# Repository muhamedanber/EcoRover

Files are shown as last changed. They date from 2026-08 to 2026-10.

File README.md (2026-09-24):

# EcoRover
A motorized recycling bin targeting food courts with a built-in fridge to store food left-overs so other people can use it. Helping saving our planet, achive SDGs 2, 8, 9, 11, 12, and 13 and increasing social Interdependence! (A Stardance project)

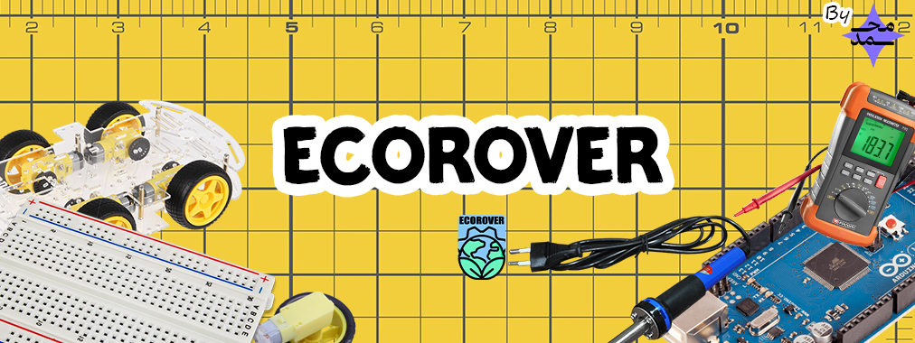
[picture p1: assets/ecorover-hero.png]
EcoRover Hero


<div align="center">
github logos
</div>
    &nbsp;&nbsp;

<p align="center"> 
  
  
</p>

</div>

</div>

> **Note on AI Usage:**  about the usage of AI: The AI is being used in this project to generate ideas, explain and debug. However, it's not used to create parts of the project that require creativity, design and construction. Also, the AI is not used more than 10% of the total project. Which counts as MADE BY HUMAN.

> **The currnt state: Working on the electronics. View [`JOURNAL.md`](./JOURNAL.md)**

---

## 1st The project and It's goals:

It’s a fancy trashcan after all XD, it has 5 wheels and sensors, and it’s gonna be wandering around in food courts with a built-in fridge. And it’s gonna store food leftovers (along with functioning like a recycling bin obviously). That way, whenever someone needs food, they can just take it without having to ask anyone, keeping their dignity completely intact. While still serving as a trash can with 4 holes so it can be recycled later.

1. 🇪🇬 Support Youth-Led Egyptian Projects: Proving what young Egyptian engineers can build from the ground up (like me XD).
2. 🇺🇳 Sustainable Development Goals: Promote both global and local sustainability by aligning with UN Sustainable Development Goals 2, 8, 9, 11, 12, and 13 (This isn’t planned; I found out halfway through the project lol).
3. 🫂 Developing Social Solidarity: Protecting human dignity while reducing food waste by making leftover food accessible without friction or embarrassment.
4. 🧠 Empower Human Intelligence: Using AI merely as a tool to increase productivity rather than as a source of creativity, since this project was developed with less than 10% AI assistance.
5. 🌍 Protect the Planet: Help protect the planet by removing organic waste and recyclables from landfills to reduce CO2 emissions and tackle environmental waste.
   
---

## 2nd Features

Here's everything packed into EcoRover to make it actually work out in the wild (
aka food courts):

* **Built-in Leftover Fridge:** Keeps uncontaminated leftover food fresh and chilled right inside the rover, giving anyone who needs a meal direct access to it without having to ask anyone or feel awkward.
* **4-Way Trash Separator:** Built into the top tier so people can sort recyclables and waste on the fly instead of tossing everything into one pile.
* **Autonomous Navigation:** Powered by an array of 8 HC-SR04 ultrasonic sensors that continuously scan all directions to dodge people, tables, and obstacles while wandering around.
* **Custom 3-Tier Modular Structure:** Modeled in Fusion 360 with a compact 40x30cm footprint and an ergonomic 90cm standing height so users don't have to bend over to toss waste or grab food.
* **Safety & Indicator System:** Includes an onboard buzzer and directional rear LEDs to signal movement (turning left, right, or stopping) so people in crowded areas see and hear it coming.
* **Dedicated Power & Driver Tier:** A low center of gravity bottom compartment housing the battery, motor drivers, and motors to keep the rover stable while moving.
* **Instant-On Active Cooling:** System firmware fires up the fridge unit immediately on boot up to ensure food stays safe from the moment the rover starts running.

---

## 3rd The CAD

The project is made of 3 main parts with a footprint of 40x30cm and moddeled into fusion 360 (my first time cadding).

* **Bottom tier:** 10cm for the battery, motors and H bridges, and counterweights if needed.

| Bottom Figure Render | Bot Bottom Figure | Bottom Body Sketch |
| :---: | :---: | :---: |
| Bottom Figure Render | Bot Body figure V1 | Bot Body sketch

* **Middle tier:** The fridge and logic board layer, 45cm.

| Mid Body Figure V2 | Mid Figure Render | Mid Body Sketch |
| :---: | :---: | :---: |
| Mid Body figure V2 | Mid Figure Render | Mid Body sketch |

* **Top tier:** The trash seprator compartment, 35cm.
  
| Top Figure V2 | Top Figure Render | Top Body Sketch |
| :---: | :---: | :---: |
| Top figure V2 | Top Figure Render | Top Body sketch |

When I first started, Gemini suggested a 40x30cm footprint and 60cm height. I just started drawing it and didn’t notice it was way too short, making the trash compartment totally inaccessible and the fridge way too tiny. I didn’t notice till I was already cadding. Since 30x40cm is a good footprint, I decided to keep that, but when I pulled out a physical tape measure and imagined the project, I found myself bending over just to reach that height! So, I pushed it up to 90cm, which feels much better. Gemini assumed I would use heavy materials, but I’m going lightweight, so Inshallah it won’t tip over.

---

## 4th The Firmware

The firmware manages everything, takes the signal from the 8 HC-SR04 ultrasonic sensors, and calculates the distance in all directions; based on that, it decides its move (moveForward, moveBackward, spinLeft, spinRight, and stop). On setup, it runs the cooling system immediately, and it also manages the safety indicators system (Buzzer and back LEDs for right and left)

Check it out at [`src-pre-release.ino`](./Firmwear/src-pre-release.ino)

---

## 5th The wiring

The wiring was done in order to create a BOM, i used fritzing even though i'm dummy at it. It went through 2 iterations, and I'm sure I've got some connections wrong, but it's only to visualize things. Both of them are missing the movmet safty system, but it has the crucial electrical safety system on V2. And to prevent electrical fire, I reached out to a fellow engineer, Mustafa Qusit (a mechatronics engineer and currently a B1 aircraft maintenance engineer at EgyptAir), to get his feedback on my circuit setup. Huge shout-out to him! He was super supportive, though he made it clear he won’t give me direct shortcuts on the electronics. He wants me to learn through trial and error, but he promised he’d step in and tell me if anything I wired is genuinely dangerous or going to go kaboom. If it’s safe, he’s letting me figure out the best way on my own, which I really respect. (Update: the boaed is changed to an UNO, check the journal to know why 🍞🍳) 

| EcoRover V2 | EcoRover V1 | EcoRover V3 |
| :---: | :---: | :---: |
| EcoRover_v2 | EcoRover_v1 | EcoRover_v3 |

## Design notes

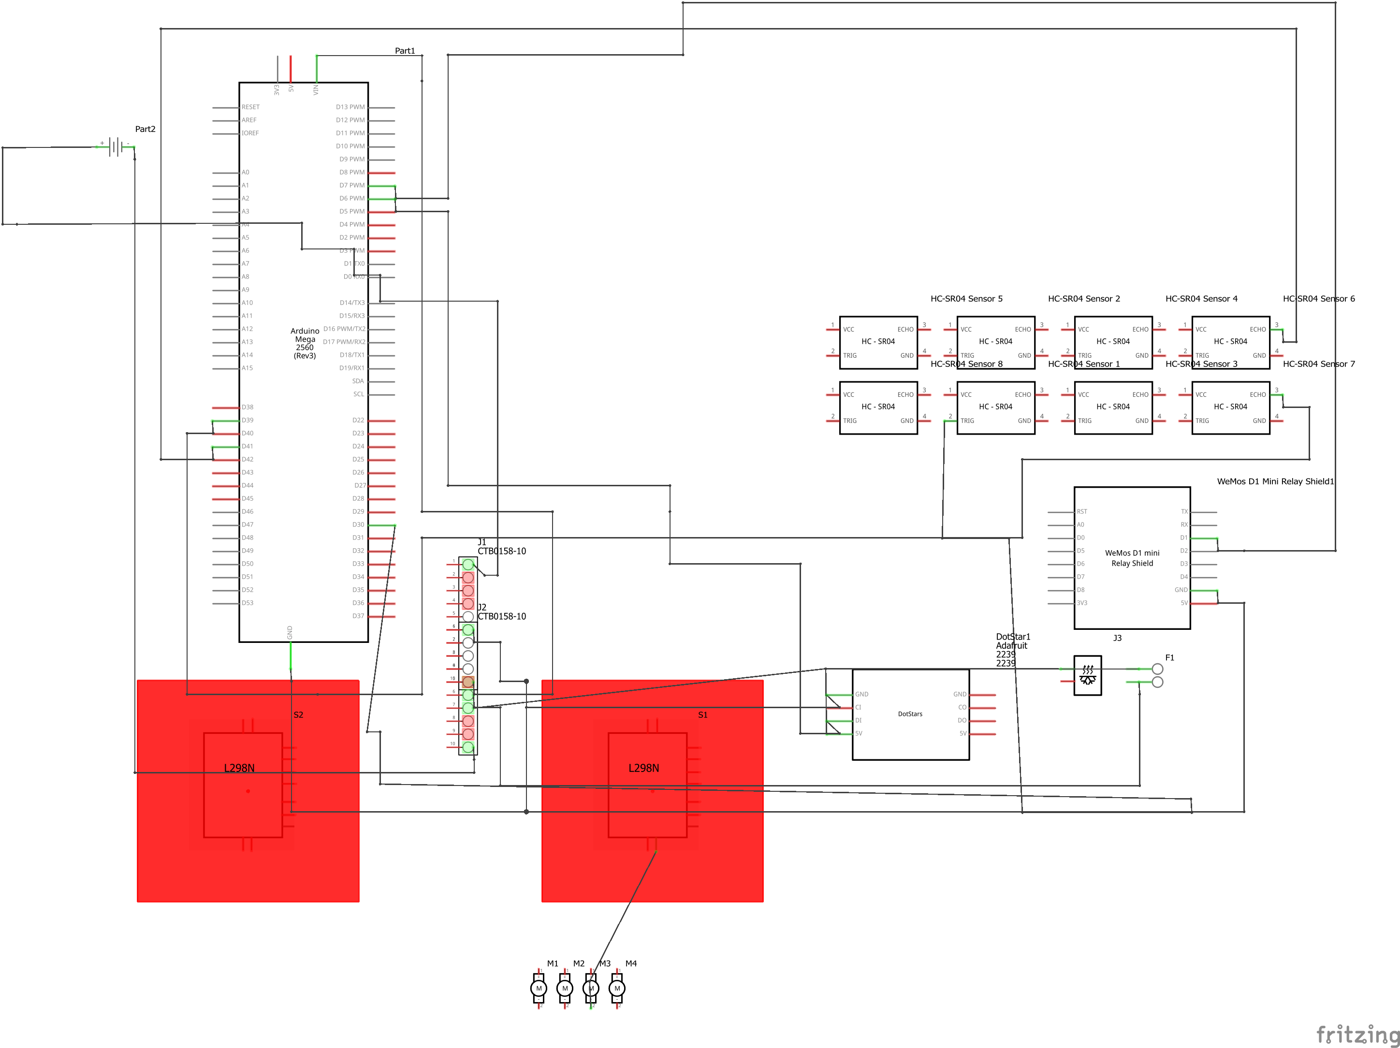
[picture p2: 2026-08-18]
Electronics/EcoRover_schem.png

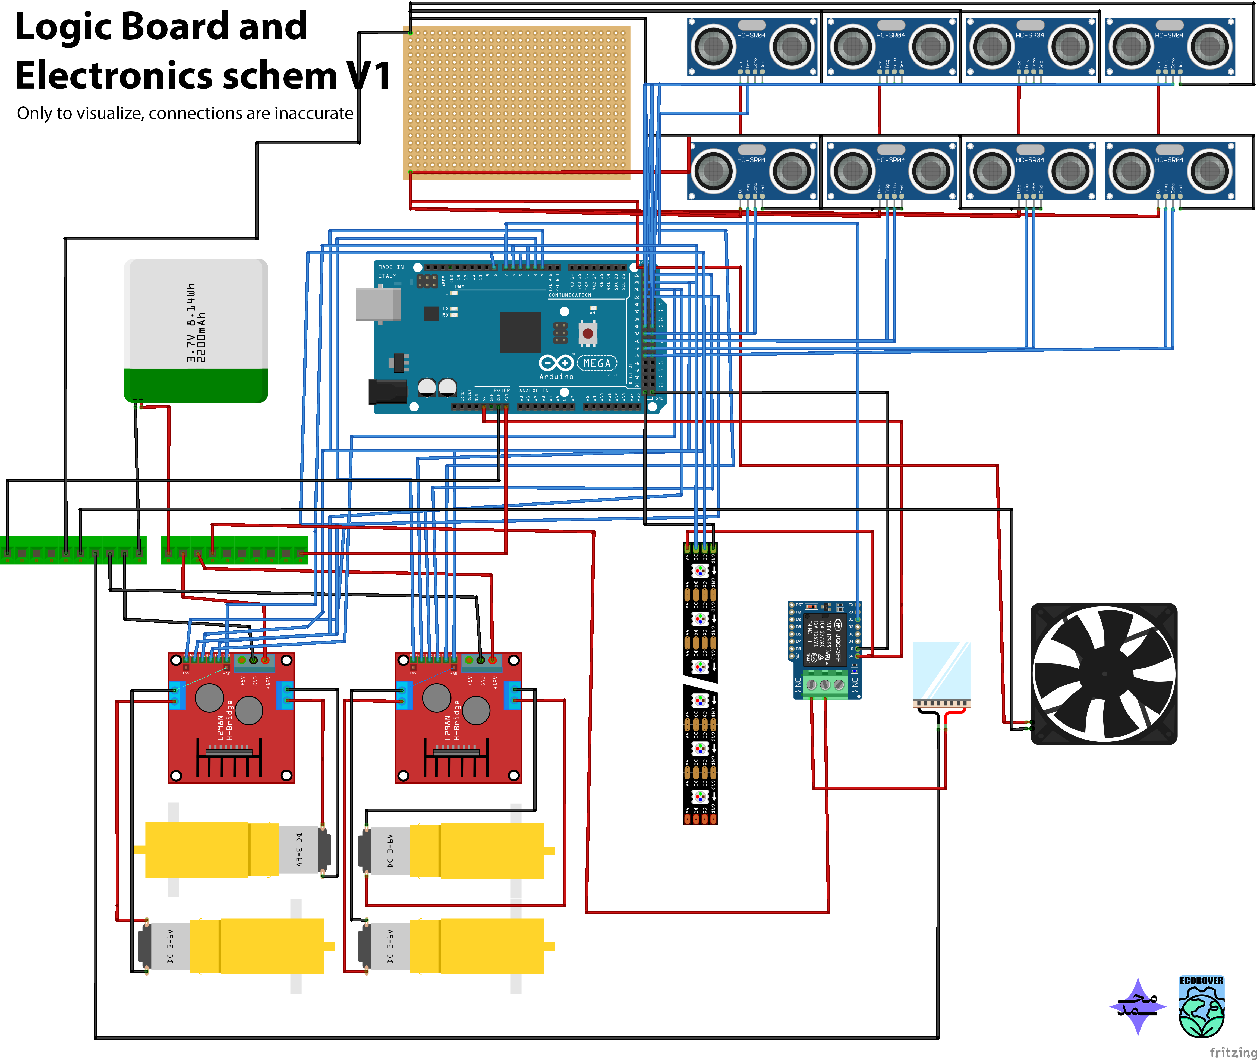
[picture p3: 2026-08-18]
Electronics/EcoRover_bb.png

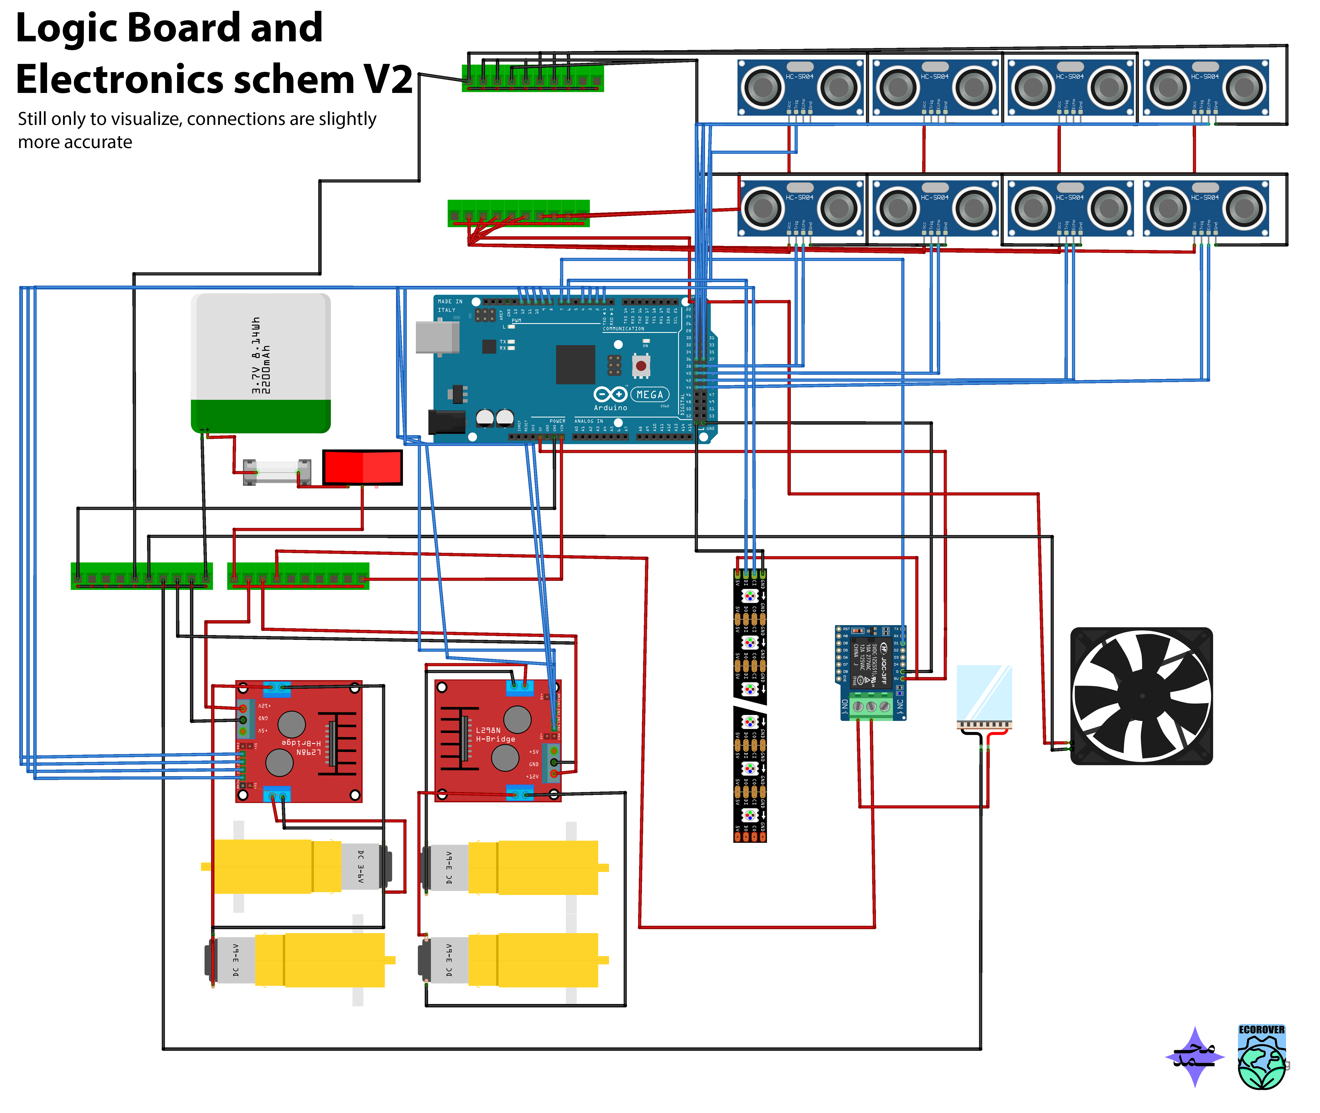
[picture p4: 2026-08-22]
Electronics/EcoRover_bb1.png

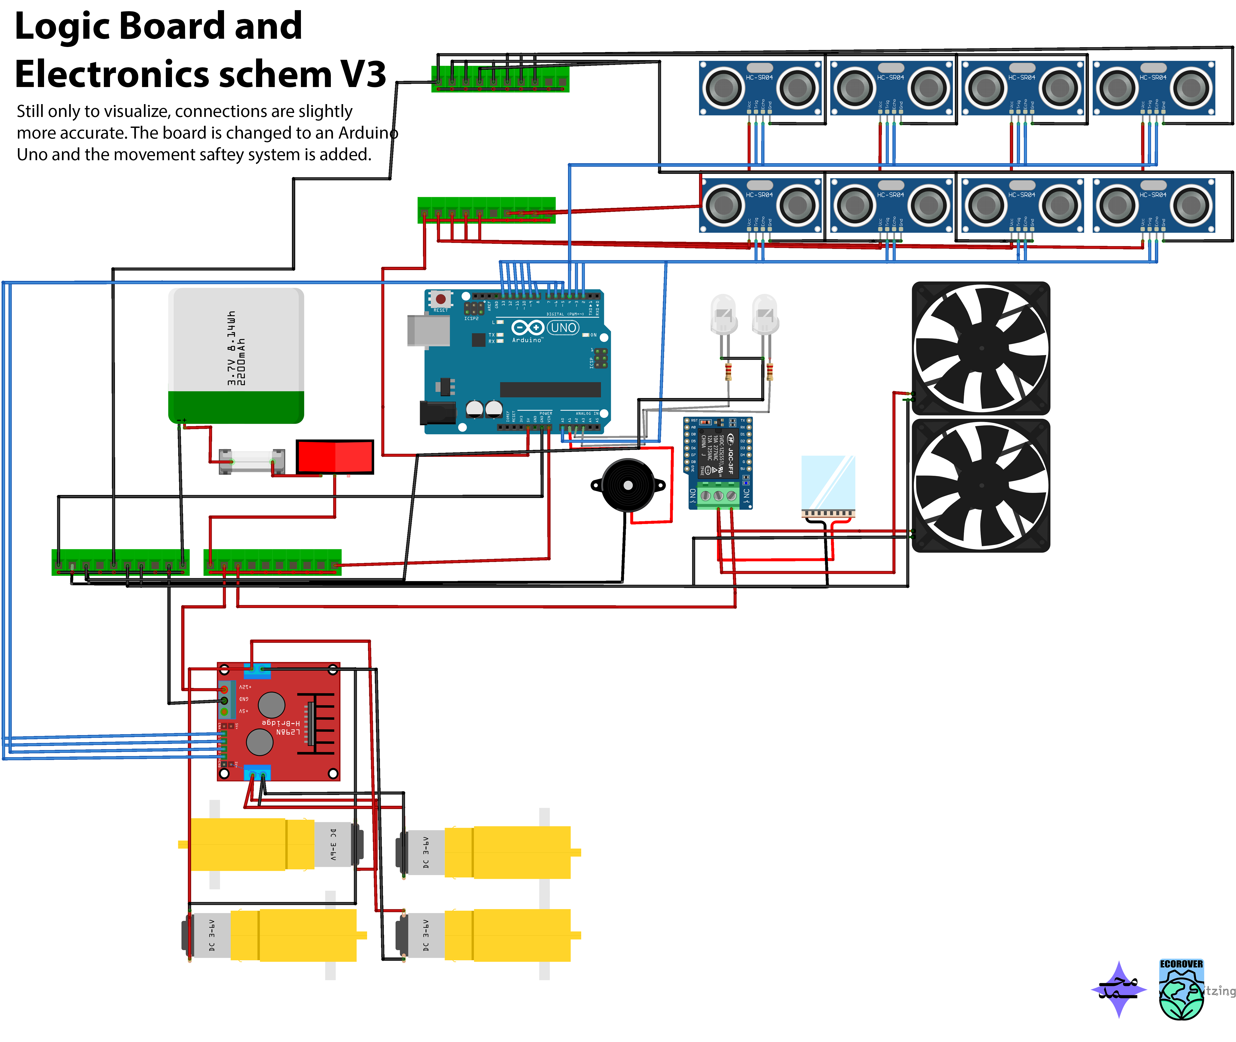
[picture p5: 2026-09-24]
Electronics/EcoRover_bb2.png

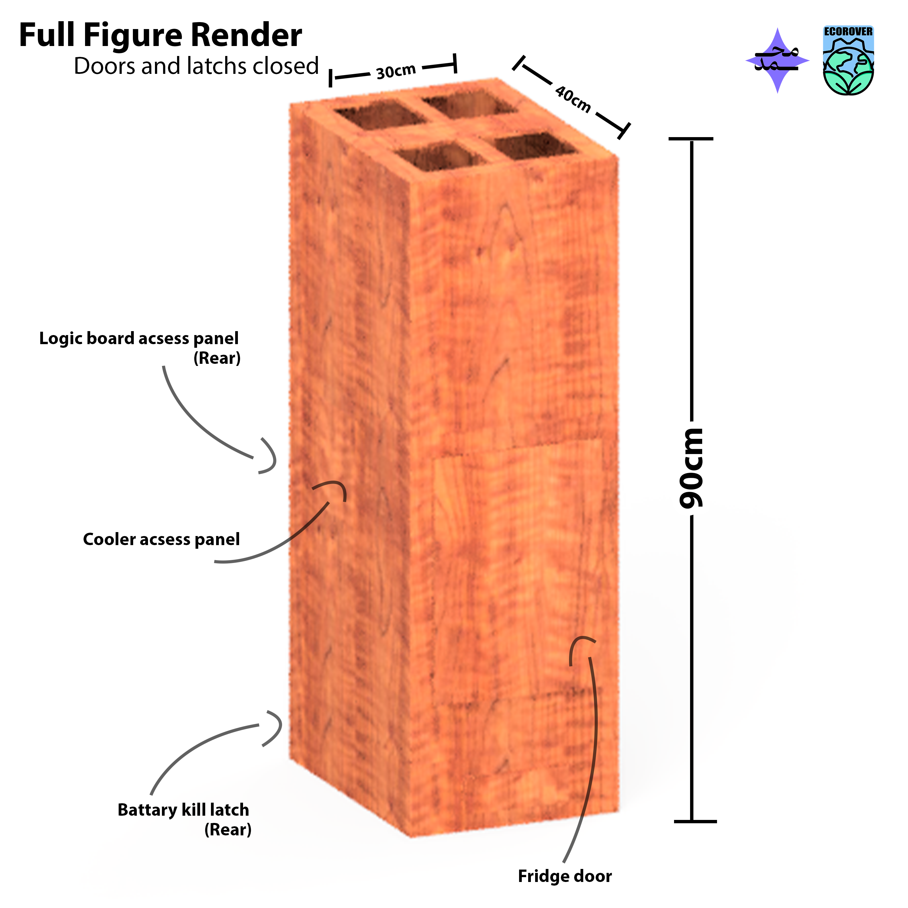
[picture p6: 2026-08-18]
CAD and structure/Render/With notes/Full Figure Render.png

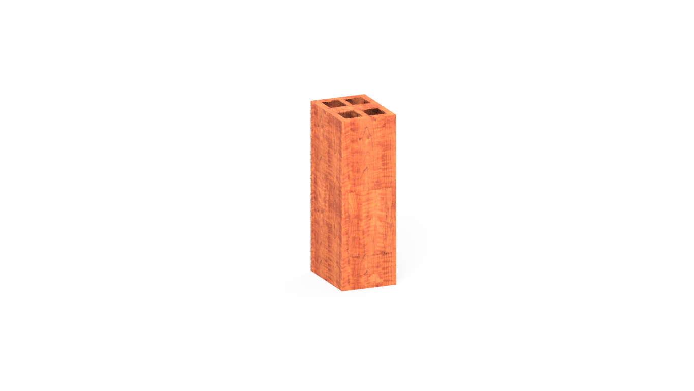
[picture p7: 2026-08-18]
CAD and structure/Render/Plain/Full View.PNG

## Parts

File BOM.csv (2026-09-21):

Item Name | Qty | Price (total) | Item link
Arduino Mega 2560 Microcontroller Board ATmega2560 | 1 | $18.84 | https://www.amazon.eg/-/en/dp/B0H9P54WB4?ref_=ppx_printOD_title_dt_b_fed_asin_title_0_0
12 Pack MDF Wood Board 12x19x1/8 Inch 3mm Thick | 1 | $8.93 | https://www.amazon.eg/-/en/dp/B0BXL9GT7X?ref_=ppx_printOD_title_dt_b_fed_asin_title_0_0
White Cork Boards - Thermal Insulation (W50cm L50cm H2cm) 4 Panel | 1 | $4.83 | https://www.amazon.eg/-/en/dp/B0BXL9GT7X?ref_=ppx_printOD_title_dt_b_fed_asin_title_0_0
Magnifier PCB Soldering Iron Stand Holder Table Magnifying Glass | 1 | $6.76 | https://www.amazon.eg/-/en/dp/B096992XJX?ref_=ppx_printOD_title_dt_b_fed_asin_title_0_0
Car Truck Motorcycle Smart Compact Battery Charger (12V, Black) | 1 | $8.70 | https://www.amazon.eg/-/en/dp/B093WSQZ9P?ref_=ppx_printOD_title_dt_b_fed_asin_title_0_0
Nylon PCB Standoff Spacer Insulating Pillars 8mm x 3mm M3 (10 Pcs) | 1 | $1.15 | https://www.amazon.eg/-/en/dp/B0FHFXK3RT?ref_=ppx_printOD_title_dt_b_fed_asin_title_0_0
64 Wire 0.9mm Pitch Multicolor Flat Ribbon Cable 1 Meter | 1 | $2.97 | https://www.amazon.eg/-/en/dp/B0GXW2SRF2?ref_=ppx_printOD_title_dt_b_fed_asin_title_0_1
APT Crimping Plier 10.5" (DW2100204) | 1 | $3.20 | https://www.amazon.eg/-/en/dp/B0CVJ5BYRB?ref_=ppx_printOD_title_dt_b_fed_asin_title_0_0
Portal On/Off Switch (Red, 16A-20A) | 1 | $0.66 | https://www.amazon.eg/-/en/dp/B091D9FG94?ref_=ppx_printOD_title_dt_b_fed_asin_title_1_0
Speaker Cable 1.5mm, 25m | 1 | $4.58 | https://www.amazon.eg/-/en/dp/B0CHQ12V9J?ref_=ppx_printOD_title_dt_b_fed_asin_title_1_1
Network Cable Stripper Tool for UTP/STP Cables | 1 | $0.56 | https://www.amazon.eg/-/en/dp/B0FCG7SDMM?ref_=ppx_printOD_title_dt_b_fed_asin_title_1_2
164pcs Heat Shrink Tube Kit | 1 | $2.36 | https://www.amazon.eg/-/en/dp/B0B2K5XJ7L?ref_=ppx_printOD_title_dt_b_fed_asin_title_1_3
Ring Terminal (4mm) 10 Pieces | 1 | $1.22 | https://www.amazon.eg/-/en/dp/B091GMSDRS?ref_=ppx_printOD_title_dt_b_fed_asin_title_1_4
Female Blade Crimp Terminal Insulated (6.3mm) 5pcs | 1 | $0.87 | https://www.amazon.eg/-/en/dp/B0DSG9QWHG?ref_=ppx_printOD_title_dt_b_fed_asin_title_1_5
Zip Ties 20 CM Cable Tie (100 Pcs) | 1 | $0.66 | https://www.amazon.eg/-/en/dp/B07V24RWDQ?ref_=ppx_printOD_title_dt_b_fed_asin_title_1_6
Total Tools Plastic Tool Box (17in-Tpbx0171) | 1 | $8.12 | https://www.amazon.eg/-/en/dp/B09SGHNJT4?ref_=ppx_printOD_title_dt_b_fed_asin_title_1_7
Soldering Flux Paste | 1 | $0.74 | https://www.amazon.eg/-/en/dp/B09GNY7P54?ref_=ppx_printOD_title_dt_b_fed_asin_title_1_8
Solder Wire 1.0mm 40/60 with Flux Core | 1 | $2.03 | https://www.amazon.eg/-/en/dp/B0GHJTWX2Z?ref_=ppx_printOD_title_dt_b_fed_asin_title_1_9
Male Crimp Cable Terminals Wire Lugs (20 Pieces) | 1 | $1.53 | https://www.amazon.eg/-/en/dp/B0DYPHFT1R?ref_=ppx_printOD_title_dt_b_fed_asin_title_1_10
TFVIRA Aluminum Foil Tape | 1 | $1.84 | https://www.amazon.eg/-/en/dp/B091BW97TV?ref_=ppx_printOD_title_dt_b_fed_asin_title_1_11
TOTAL Cutter Tools TMT511826 | 1 | $1.64 | https://www.amazon.eg/-/en/dp/B0922TVXX3?ref_=ppx_printOD_title_dt_b_fed_asin_title_1_12
SMART ZOOM Battery - UPS DC 12V-7Ah | 1 | $19.11 | https://www.amazon.eg/-/en/dp/B0CCLJNP8D?ref_=ppx_printOD_title_dt_b_fed_asin_title_0_0
Mini Blade Fuse Kit Automotive (10 Amp, 10 Pieces) | 1 | $2.07 | https://www.amazon.eg/-/en/dp/B0CCLJNP8D?ref_=ppx_printOD_title_dt_b_fed_asin_title_0_0
Heat-Resistant Adhesive Tape 6mm (Kapton Tape) | 1 | $1.91 | https://www.amazon.eg/-/en/dp/B0F2VPMDZQ?ref_=ppx_printOD_title_dt_b_fed_asin_title_0_0
iLock Electrical Tape - 10 Meters - Black | 1 | $0.48 | https://www.amazon.eg/-/en/dp/B09VL7CM28?ref_=ppx_printOD_title_dt_b_fed_asin_title_0_1
DT9205A Digital Multimeter Voltmeter Ammeter | 1 | $7.04 | https://www.amazon.eg/-/en/dp/B08YNCV5B1?ref_=ppx_printOD_title_dt_b_fed_asin_title_0_2
Jadever JDMT4310 ABS Steel Measuring Tape (3M x 16mm) | 1 | $0.77 | https://www.amazon.eg/-/en/dp/B0DPQR1RT7?ref_=ppx_printOD_title_dt_b_fed_asin_title_0_3
30g Grey Thermal Grease Paste Compound Silicone | 1 | $0.64 | https://www.amazon.eg/-/en/dp/B087QRN41Y?ref_=ppx_printOD_title_dt_b_fed_asin_title_0_4
A65061-003 Cooling Computer Fan and Heatsink 12VDC | 2 | $5.46 | https://www.amazon.eg/-/en/dp/B0FPD2F2V1?ref_=ppx_printOD_title_dt_b_fed_asin_title_0_5
A65061-003 Cooling Computer Fan and Heatsink 12VDC | 1 | $3.27 | https://www.amazon.eg/-/en/dp/B0D31QQF9B?ref_=ppx_printOD_title_dt_b_fed_asin_title_0_6
INGCO Electric Soldering Iron 70W (SI01606) | 1 | $5.12 | https://www.amazon.eg/-/en/dp/B0G8M3CL3N?ref_=ppx_printOD_title_dt_b_fed_asin_title_0_7
Round Magnets (17 mm Diameter, 12 Pieces) | 1 | $1.91 | https://www.amazon.eg/-/en/dp/B0GSPKLK6X?ref_=ppx_printOD_title_dt_b_fed_asin_title_0_8
Inline Fuse Holder for ATC/ATO Blade (10AWG, Waterproof) | 1 | $3.38 | https://www.amazon.eg/-/en/dp/B0H1SBFDZS?ref_=ppx_printOD_title_dt_b_fed_asin_title_0_9
HC-SR04 Ultrasonic Module Distance Sensor | 8 | $10.63 | https://www.amazon.eg/-/en/dp/B091FS9YR9?ref_=ppx_printOD_title_dt_b_fed_asin_title_0_0
Gear Geared Motor Dual Straight Shaft | 1 | $3.67 | https://www.amazon.eg/-/en/dp/B091FT4H11?ref_=ppx_printOD_title_dt_b_fed_asin_title_0_0
Dual H Bridge DC Stepper Motor Controller (L298N) | 2 | $3.97 | https://www.amazon.eg/-/en/dp/B07NDYWN26?ref_=ppx_printOD_title_dt_b_fed_asin_title_0_1
Relay Module 24V (1 Channel) Active Low Level Trigger | 1 | $1.66 | https://www.amazon.eg/-/en/dp/B0DY53Q7VC?ref_=ppx_printOD_title_dt_b_fed_asin_title_0_2
TT Motor Plastic Tire Tyres Wheel DC 3-6V | 1 | $4.25 | https://www.amazon.eg/-/en/dp/B099Z85573?ref_=ppx_printOD_title_dt_b_fed_asin_title_0_3
Ivy Grip Tape Double Face Nano Adhesive (3M) | 1 | $0.84 | https://www.amazon.eg/-/en/dp/B091J4DSZ8?ref_=ppx_printOD_title_dt_b_fed_asin_title_0_4
TEC1-12706 Thermoelectric Cooler Peltier 12V | 1 | $3.27 | https://www.amazon.eg/-/en/dp/B091D1VTGZ?ref_=ppx_printOD_title_dt_b_fed_asin_title_0_5
TB1512-12 Pin Fixed Barrier Terminal Block (15A-600V) | 4 | $7.73 | https://www.amazon.eg/-/en/dp/B0H6JGZLQC?ref_=ppx_printOD_title_dt_b_fed_asin_title_0_0
INGCO 7 Inch Folding Pruning Saw SK5 Steel | 1 | $3.86 | https://www.amazon.eg/dp/B0GS4SJT35?ref_=ppx_printOD_title_mob_ap_fed_asin_title_0_0
Caster Wheel | 1 | $1.73 | https://www.amazon.eg/gp/aag/main?ie=UTF8&seller=A1G5VPUVPXBMQ6
 |  | 173.23 (In total and after conversion from egp and adding shipping)

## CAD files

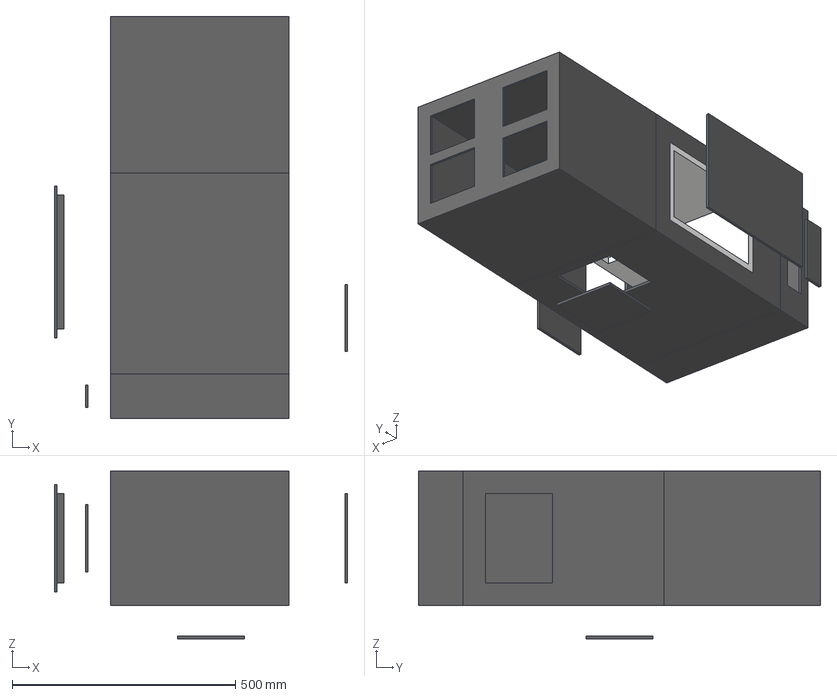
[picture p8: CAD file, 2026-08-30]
CAD and structure/EcoRover chase.step
656.0 x 900.0 x 375.0 mm

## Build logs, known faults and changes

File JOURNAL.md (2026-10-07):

Heyy welcome to my journal <3
This will have both the devlogs and the boring details I dont mention in the devlogs.

## Devlog #1: Taking EcoRover Off the Slideshow
– jul 12th 2026 –

Let me be honest for a second. A while ago my school pressured me and my friends into entering a local hackathon. I had exactly 24 hours to brainstorm an idea, throw a team together, build a quick prototype, and set up a booth for the final judging visit.

I came up with a concept called EcoBot, which was a smart, autonomous recycling bin and bread leftovers collector designed for schools. On paper it was cool but in reality? It never actually got built. It lived and died on a slideshow to check a school box.

But I actually liked the concept. So for Stardance this summer I decided to bring it back and build it for real. Except this time there’s no rush, no team, and no cutting corners to pass a class. I’m going completely solo as EcoRover.

**A quick BG about me:**
I’m Mohamed Anber, an 18yo Egyptian teen who happened to join Stardance in the final year before I’m too old for it. For the last 3 years I’ve been volunteering as an EMR with the Saudi Red Crescent Authority and a Tech Dept. supervisor with the Egyptian Red Crescent. I’ve built some pretty cool projects before (u can check them out on my website btw: https://muhamedanber.space/) though none of them involved trying to keep bread fresh while driving a fancy motorized trash can around. We’ll try to make smth good.

### 🛠️ The new Blueprint & The Specs
I’ve changed the idea partially. It’s still a fancy trashcan after all, but instead of going around at schools, it’s gonna be for food courts with a built-in fridge. So instead of bread remainings, it’s gonna take food leftovers and save them. That way, whenever someone needs food, they can just take it without having to ask anyone, keeping their dignity completely intact.

I’m building a triple-decker chassis:
* **Bottom tier:** Handles the heavy power and movement.
* **Middle tier:** Houses an insulated compartment kept cold by a Peltier cooling module to keep those leftovers fresh.
* **Top tier:** Handles sorting whatever thrown into to recycle later.

**The Tabletop MVP Specs:**
* **The Brain:** Arduino Mega 2560 (absolutely need the massive amount of IO pins).
* **The Eyes:** 4x (later got rasied to 8) HC-SR04 Ultrasonic Sensors mapped North, South, East, and West for 360° obstacle avoidance.
* **The Muscle:** 4x DC Yellow Smart Car Motors paired with dual L298N H-Bridge drivers. I wanted to go with mecanum wheels at first but it’s gonna be too much of a hustle rn, so we’re just doing differential drive.
* **The Fridge:** Since an actual 12V mini fridge is gonna be soo heavy, expensive and just not practical, I’m using a TEC1-12706 Peltier Thermoelectric Cooler switched via a 12V Relay module.

### 📹 Current Status
That’s pretty much everything I’ve got down so far. Plus, I’m working on a long video to document the whole journey, so I’ve already scripted and filmed the first part-ish. On to the CAD chaos...

---

## Devlog #2: The CAD Nightmare and the New Dimensions
– From jul 15 to jul 23rd 2026 –

Alr this whole CAD thing is a total headache.

When I first started, Gemini suggested a 40x30cm footprint and 60cm height. I just started drawing it and didn’t notice it was way too short, making the trash compartment totally inaccessible and the fridge way too tiny. I didn’t notice till I was already cadding. Since 30x40cm is a good footprint, I decided to keep that but when I pulled out a physical tape measure and imagined the project I found myself bending over just to reach over that height! So, I pushed it up to 90cm, which feels much better. Gemini assumed I would use heavy materials, but I’m going lightweight, so Inshallah it won’t tip over.

Now the new dimensions are:
* **Bottom tier:** 10cm for the battery, motors and H bridges, and counterweights if needed.
* **Middle tier:** The fridge and logic board layer, now pushed from 35 to 45cm.
* **Top tier:** The trash compartment, changed to 35cm instead of 15cm so people can actually use it.

A quick heads up if you forgot: It’s a fancy trashcan after all, it has wheels and sensors and it’s gonna be wandering around in food courts with a built-in fridge. And it’s gonna store food leftovers. That way, whenever someone needs food, they can just take it without having to ask anyone, keeping their dignity completely intact. While still serving as a trashcan with 4 holes so it can be recycled later.

Back to the story XD: This was my first time ever cadding, so I drew everything in Photoshop first. Then I watched a 20 minute video and figured the rest out in Fusion 360 on my own. Fusion was pretty heavy for my laptop, so it was a nightmare when parts failed and I had to remodel them from scratch. And in the end when I was rendering it looked a bit weird but im not gonna change it cuz i’m exhausted tbh and my patience is running thin. Also during cadding, I added some access panels for maintenance and emergency latches in case god forbid we needed to kill the power.

As for the video, I decided not to script it word for word anymore, so I’m just running the camera and letting it happen. Up next: tackling Fritzing and dealing with real-life logistics...

---

## 📌 Daily Log Updates

### Jul 18th, 2026
Today I got this weird notification saying that I can't ship my project through stardance and I've to do it through outpost which got me confused cuz outpost is already over. i asked and they sent me a migration to outpost file only for my surprise that the file has been taken down, I'm really confused and A LOT others on slack but I wont stop the project's pace so I'm gonna continue using stardance to log hours untill they clearify more.

---

## Devlog #3: Pivot, Wiring Struggles, and Learning the Hard Way
– From Aug 13th to Aug 18th 2026 –

Alr, a lot has happened since Devlog 2!

First off, I traveled back to Egypt on August 13th, and the internet here is honestly making video editing a whole mission. I was originally using Google Vids and its AI auto-trimmer to cut out silences from my documentary footage, but uploading massive video files to Drive here completely destroys the internet plan and takes forever. I tried switching over to Premiere Pro (which my laptop usually handles pretty well), but it started lagging badly and making my laptop run super hot. After wasting about 3 hours trying to get it to run smoothly with zero luck, I decided to completely pivot: I’m setting aside the documentary video for now and focusing on keeping a detailed journal directly in this repo instead, uploading as many progress time-lapses here as I can.

On the hardware side, I started modeling the electronics in Fritzing. Even though it’s only my second time using it, the connections are insanely annoying to trace out. I’m pretty sure some of the schematic lines look wrong on paper, but I have the whole circuit clear in my mind, so I just modeled it anyway to visualize the layout. I’ll make sure everything is hooked up correctly when I actually assemble the physical board.

I also finalized the Bill of Materials (BOM) and did some price comparisons across different stores. To keep things safe, I added a few crucial safety measures like an inline fuse and a rocker switch so nothing accidentally shorts out or catches fire.

Speaking of not blowing things up, I reached out to a fellow engineer, Mustafa Qusit (a mechatronics engineer and currently a B1 aircraft maintenance engineer at EgyptAir), to get his feedback on my circuit setup. Huge shout out to him! He was super supportive, though he made it clear he won’t give me direct shortcuts on the electronics. He wants me to learn through trial and error, but he promised he’d step in and tell me if anything I wired is genuinely dangerous or going to go kaboom. If it’s safe, he’s letting me figure out the best way on my own, which I really respect.

Now it's time to actually get the funding sorted and get my hands on the physical parts...

---

## 📌 Daily Log Updates

### Jul 31st, 2026
Today I got another notification saying they've resolved the hardwear shiping through stardance and i can continue using it to ship and fund my project. also they've shifted there timelapsing to Laps which is a seprate platform that connects to hackatime and lookout instead of the old built-in one they were using.

### Aug 18th, 2026
Today I worked on this GitHub repo to make it presentable.

### Aug 20th, 2026
Today I'm going to open a USD account so I can receive the funding and start building it IRL. Also spending time today updating those faulty schematics from the first Fritzing run so everything is clean and ready. and maybe check the post office on my way cuz my stickers are stuck there lol.

### Aug 22nd, 2026
Alright so the post office told me to fudge of and they don't have my stuff so it's gone. and today i applied for funding which didn't ask for a bank account yet so idk why i didn't do it earlier, I'll work again on the electronics to make it more logical and add the safty messures i wanted to add.

### Aug 24th, 2026
Today A LOTTT happened, First I recived my card and my USD bank account got activated, only for me to find out that I don't need one and the fund is a card grant 🤡. Also the guy who's handling the grants i heard he's out of office but i'm supposed to get it in a week. but that teaches me that i really need to stop making asumption and actully check the process of everything before I take any actions. tbh my fire started diming, like it got streatched soooo long that lol i got bored. but inshallah it will be finished by the end of next week -I hope-. Also i'm gonna reach out to verynile which is is an Egyptian social initiative that cleans plastic waste from the Nile River using specialized boats and volunteer events. The project pays local fishermen to collect trash and employs local women to upcycle the plastic into new products. Through these cleaning and recycling efforts, they protect the environment while supporting locals economically -Espicially women-, and they have a really cool CNC machine that engraves on the plastic they produce, and since our visions really overlap in multiple ways (Egyptian projects, Sustainability, Social solidarity, and saving the planet and there designs are human made -by Qorsaya women- and not AI.) I want them to create the plate that will have my logo and the project's and Made In Egypt emblem on so I can attatch to the rover and maybe even the whole chasee if they're up to it 🫣. Lastly I realized i've not write the project goals which are 5 and are included in the readme.md now. I realized that i forget timelapsing a lot of times, like theres almost 5h total time that isn't lapsed 🤦🏻‍♂️.

### Aug 27th, 2026
well, well, well. they sent me this today (good work! however, your README seems to be ai-generated; please rewrite it without AI! your BOM prices also aren't in USD, and you should be able to source from cheaper places like aliexpress. make sure to add images in the README as well! good work so far!) I mean i can do everything mentioned but that aliexpress part..... ughhhh. well i can't due to two things. 1st is the crazy long shipping thime for Egypt, + This site is extreamly moderated in here, like probably it wont enter egypt lol.

### Aug 29th, 2026
They still didn't reply with the funding after i resolved the problems so i reached out to the head of hardware@stardance. they still didn't reply. In the meantime i really dont have anything to do. my personal life is a mess since i started the project and it's getting messier. so i really hope i finish this project ASAP. i still dont even know if im getting back to ksa or not yet. so the timeline is really not guaranteed. Also I've contacted yasmin@verynile, she's a really nice woman but the inconsiderate me contacted her on friday 🤦🏻‍♂️ (it's a holiday in egypt and the arab world like sunday and saturday in the US/Europe). but she was really nice and understanding and told me to contact her sunday (tomorrow). so i'll do so. for today I had a plan to keep this project opensource for individuals and tinkerers, but i dont want any commercial use without my authorization, i was planning to register it as a utility model but then i cancelled cuz its too much of a hassle. so I'll get a DOI and use CC-BY-NC for everyting apart from the code and MIT for the code. and thats it for today.

### Aug 30th, 2026
Hey, its me again, i just woke up to this message (Hello!

Congrats on this project! This is a really good idea that genuinely helps our planet. However, you are missing the firmware for your project. In addition, you are also missing the .step files in the repo for your CAD.

Lastly, make sure that you are following the file structure for submitting hardware projects. You can check it out here: https://stardance.hackclub.com/resources/shipping-hardware

Once these changes are made, and everything is good, we will take another look, and if everything is good, you will be approved! :D). the goal is simple right? get a pre-release firmwear and a STEP file, WRONG!, cuz for somereason fusion panicked and s**t itself when i lunched it and now its been "restoring" for the last 20 mins. i got a firmwear (some poor guy's opensource code for obsticle detection rover that i ripped then modified with google's gemini) i really don't know if this is still made by human after what just happened cuz made by humans requiers 90%+ human work for the whole project but i mean the code itself is human written it just tweaked it and the script is one tiny thing in the whole project so fudge it tbh. Also I've contacted verynile again and they said they can't do the chasee for free cuz this is the work of the fishermen and the local women in the workshop but she'll see if they can make the plate and contact me again. ill finish fusion's drama and resubmet for funding and then continue sleeping.        ----- 3 hours later: didn't sleep but worked on the plates they gonna make and changed the licensing from CC-BY-NY 04 TO CC-BY-NY-SA 04 on here and zenodo.

### Aug 31st, 2026
Just got off the phone with Sama@VeryNile. they can do it for free yayyy 🎉. I'm really happy it worked out like this, im supposed to go pick it up by thursday and have a tour there, and for my luck it'll also be a volunteers day soooo maybe i'll go 😁 (IDK really yet but i guess it'll be so much fun). thanks again VeryNile for your generosity and thanks stardance for making all of this possible. and for this I've added a note on the plate thanking both parties. with that being said, i guess thats it for today ill just follow up with Sama till we see what works with there CNC cuz they've a 3mm drilling bit which is too big for small details, the 1mm just breakes when they try to use it. 

### Sep 1st, 2026
Vibe edited the code (the original one was open source) but it's still the original code just with added futures not removing anything from the original one, and vectorized the design so the CNC machine can engrave it. Also i've wrote the devlog so i add the 7 hours i made. Also a lot of things went out of stock so I've to sacrifice things to pay for the most important or pay out of pocket.

---

## Devlog #4: Funding Loops, Licensing Hassles, and a Huge Local Win

– From Jul 31st to Sep 1st 2026 –

Man, August was an absolute administrative marathon.

First came the banking wild goose chase. I went through the whole process of opening a brand new USD bank account in Egypt specifically to receive the project grant, only to find out right after activation that funding was being issued as a card grant anyway 🤡. Total facepalm moment, but a good reality check to stop making assumptions before jumping through hoops.

To make matters more frustrating, the grant review hit a few speedbumps. Stardance flagged my initial README as AI-generated and asked me to clean it up, fix my BOM pricing into USD, link standard STEP files, and push the initial firmware to the repo. I also ended up building off an open source obstacle detection script to get the base firmware pre release ready. Between waiting on grant replies, keeping up with these repo adjustments, and dealing with some heavy life updates floating in the background, things got pretty exhausting and its been already 8 days.

Luckily, the highlight of this entire month came from reaching out to VeryNile. If you don’t know them, they are a fantastic Egyptian initiative that cleans plastic waste from the Nile using local boats, pays local fishermen to collect the waste, and employs local women from Qorsaya island to upcycle that plastic into new materials. They have a CNC machine that engraves directly on their recycled plastic sheets.

Since our missions align so closely on sustainability and local impact, I wanted to collaborate with them on a custom plate for EcoRover that features our logos and a “Made in Egypt” emblem and some other logos. After a couple of calls with their team, Sama from VeryNile confirmed they would engrave and donate the custom plate for free! 🎉

with that the core design, licensing (CC-BY-NC-SA 4.0 for the hardware assets via Zenodo -to get a DOI- and MIT for the code), and local partnerships are locked in.

Next up: picking up the custom plate from Qorsaya and starting physical assembly!

---

## 📌 Daily Log Updates

### Sep 03rd, 2026
I'm still waiting for the funding, there's nothing i've to do and i'm really bored. idk why this time the review is taking so long.

### Sep 05th, 2026
It's been 6 days with radio silence, i really started to lose fire and my personal life is taking a steep turn and its getting a but tough. but in that darkness 2 good things happened. 1st I've just finished writing my first research ever. It's a goal that i had since childhood that i want to publish a research before I'm into uni, and Alhamdullah it happened (well, the writing part) I've had the idea and started working in last december but I was messing around and i needed guidance. I applied for lumiere breakthrough and got rejected so fast 😂😭. Then i couldn't find any program that would accept me so i decided to fudge around and find out and do the research on my own anyway (sounds easy but i was already emotionally unstable for personal reasons) and i took off working a tiny bit every few days due to how busy my life already is. now I've just submitted it to a journal and waiting for the peer-reviewing to end. Anyways i know i yapped a lot lets get back to the project which is the 2nd happy news, Tmrw im gonna get the plate from verynile, marking the very begining of the physical build.

### Sep 06th, 2026
Today was crazyyy, I went to VeryNile and met with Maryam and Sama and they were really hospitable. They showed me around and told me everything about VeryNile which is really impressive. and omg the plate looks super good, A REALLY huge thank you for all of them for this effort, and I'm pretty sure we're gonna do more beautiful things in the future together.
Snapchat-947293805

### Sep 07th, 2026
😁😁
<table>
  <tr>
    <td>Bottom layer Render</td>
    <td>Mid layer Render</td>
    <td>Top layer Render</td>
    <td>Full Figure Render</td>
    <td>Schem V2</td>
  </tr>
</table>

### Sep 10th, 2026
Still radio static. the most terrifying part that i genuinely dont know if i'm returning to saudi arabia and if it's soon. like what i went there and the funding came after that, 177usd wont get me there half of the stuff i'm gonna buy from here. also my personal life is.. idk really its getting messy in ways and orgnized in others, i really dont know. and i don't really have someone to talk to about this so thats why im here talking with you guys (IDK if anyone would read this far, must be a secret lover if this intrested XD XD). Anyways i got a parttime remote job that i'll focus on slightly in the next days.
- later into the day: I've DMed the same guy who reviewed my project before and he told me he'll look into it, then he returned the project again cuz of (Hello!

Great work on this project! However, I know based off of the dms that we had, that you haven't coded for a while, but that is the whole point of stardance! You are to code yourself. You can't just open source something and use AI to make it yours. Please make the code yourself.). So ill try to make it myself even though i suck in coding but we'll see whats going on.
- later into the day.. again: Its 0306 IN THE MORNING, im tired but i'm done. technically it's sep 11th but i still havent slept so for me its still today

### Sep 11th, 2026
I want to shout out to Jay, the hardware reviwer i've been contacting for a few days. he is really patient with me as my project needed a lot of fixes before he can issue the funding. and he's still following up with me. a big thank you!

### Sep 14th, 2026
Today, the funding was approved!!!!!! I woke up to the best notification ever, baby. And in 3 hours the money evaporated lol 😂. But 2 bad things happened and then 1 good thing came and overwrote everything bad that happened alhamdulillah. Future Electronics (which was the supplier for the freaking Arduino and the LiPo battery) doesn't accept card payment, and RAM which was my second biggest supplier, doesn't accept foreign cards. So I had to go to uncle Amazon, which is slightly more expensive for a lot of things. That's when I googled "177 usd to egp" which came out to 9,158.42 EGP which is wayyy more than the 8 grand I wanted at first. For the first time ever, the EGP drowning against the USD worked in my favor. I didn't just buy everything, I was planning to cut off some things and I didn't, thank God! The card is now at $0.64 USD after I bought everything the project needed. Arrival is scheduled starting tomorrow and over the next few days, with a few items arriving every day. It's 43 orders and 58 individual pieces and tools. The shipping added up a little just a few dollars less than $5. and man the dopamine hit of shopping is still in me cuz lowkey This is the biggest Amazon order of my life. The challenges were two. first the LiPo battery needed to go cuz only future sell them, they're dangerous, hard to find in Egypt, and I couldn't find any balance chargers online. That gets us to problem number 2, since it's a card grant, I can't use local shops that don't take card payments. I'm recreating a BOM with the new things and i'll push it when it's ready, thanks again to Jay@Stardance hardwear <3

---

## Devlog #5: Funding Cleared, Amazon, and Currency stuff
– From Sep 1st to Sep 15th 2026 –

Today, the funding finally got approved!!!!!!

I woke up to absolute green lights and the best notification ever. Naturally, within 3 hours the money completely evaporated lol 😂. But honestly, two major roadblocks popped up back to back, only for one good fate to come through and overwrite all the stress thank god.

The first headache was payment processing. Future Electronics (who was supposed to be my primary supplier for the Arduino Mega and the main LiPo setup) doesn’t accept card payments. Then RAM Electronics whicj is my second biggest supplier, turned out not to accept foreign cards. Since the grant was issued as a virtual card, that meant zero local offline shops and zero local sites without online gateways.

So I had to pivot entirely to uncle Amazon who is slightly more expensive for a lot of things here, so I immediately googled "177 usd to egp". The conversion hit 9,158.42 EGP (which was wayyy higher than the original 8 grand budget I calculated weeks ago) i thought i’d need to cut corners but thank god the extra grand payed for the price difference!

For the first time in history the EGP dip against the USD actually worked in my favor. I didn’t just cover the costs I was fully prepared to start axing components from the build, but thank God, I didn’t have to cut a single thing. After checking out every single line item the project needed, the card balance is sitting clean at exactly $0.64 USD.

The order log is wild its 43 individual orders totaling 58 pieces, modules, and physical tools. Overall shipping added up to just under 5 bucks. The sheer dopamine hit of smashing that checkout button is still running high because lowkey this is officially the biggest Amazon order of my life. Deliveries start rolling in tomorrow (aka today cuz i still havent slept and its 0450am) and will keep trickling in over the next few days.

We also had to make two crucial hardware adjustments on the fly

The LiPo Swap: The original LiPo battery plan had to go. Future was the only local vendor stocking the specific pack, they’re notoriously hazardous to ship/store, and finding proper balance chargers online locally was an absolute dead end. We’re swapping the primary power delivery to a safer, more accessible Lithium Ion setup.
Card Only Sourcing: As mentioned, because this is an international card grant, any vendor without structured online payment processing had to be swapped out of the supply chain entirely.
I’m currently in the middle of rebuilding and restructuring the entire BOM to reflect the exact Amazon components, specs, and updated unit prices. I’ll push the updated BOM file directly to the GitHub repo as soon as it’s finalized.

Huge thanks again to Jay @ Stardance Hardware for helping clear the administrative loops and getting the grant active! <3

Immediate Action Plan
Unbox and inspect all 58 individual components upon arrival over the next few days
Complete the updated BOM spreadsheet with exact Amazon item links and prices
Push the updated BOM.md and CAD changes to the main GitHub repository
Lay out the real-world bench assembly and start initial power testing

---

## 📌 Daily Log Updates

### Sep 17th, 2026
All of the stuff arrived today alhamdullah with no problems, even some of the sellers were kind enough to send me a little gifts (A  Red Mike Wazowski which was weird but cute and what's weirder that it came with the Arduino??. but it's cute none the less. Also a lot of thank you cards and even a car freshener that came with the fues since it was a car fuse), but unfortunately I'm super sick lately and today is the peak of it (my bones aching so bad). but idk the excitement is too much so I guess I'm gonna start working on it today, and also push a new BOM like Jay@Stardance told me. I'll update this entry if my boneache allowed me to on anything physical today, also I had to spend some money out of pocket for some screws and hinges that I forgot to include in the BOM 😂🤦🏻. also I forgot to mention that the only 3mm plywood I found on Amazon that can work with me is ≈30×50cm. now the ideal size for the EcoRover is in the CAD subfolder and to work with these 30×50 panels I've 2 options. the first that we join every 2 together and then cut the remainings, or we just make this first prototype with what we have without changing the dimensions of the original EcoRover which is what I'm gonna do. that's it for today, byeee.
- later into the day: well I decided to tough it out and work anyways. and I discovered something quite new, handsaws are dangerous kids, this one I have is foldable and it has a button to release it. I clicked it with my hand inside and u can imagine the rest, but thank God I'm okay. just a little cut that stopped bleeding after a few seconds, also I was clumsy with the saw at first but I managed to do the middle layer outer shell with a place for the fridge and the logic board and the latching system that will make it connect with the lower level. I'm so tired and I made a mess now, I'll clean it up and crash. see you tomorrow.

### Sep 18th, 2026
when I finished I was so exhausted that I blacked out and I'm writing this entry the day after lol. but I finished the highest layer which is the trash separator, I had to stop working in the living room after a threat made from my grandma personally for filling the living room with sawdust 😂, now I work in the balcony and it's great in there, I became friends with the mouse in there XD. bodyache became super strong, not uncomfortable anymore but painful. tomorrow (aka today) I'll make a better latching system to make the 2 layers latch together and hopefully I'll do the lowest part which will hold the battery and then start the electronics god willing.

### Sep 19th, 2026
Today I finished the last layer which is all the way down. now the latching system, the doors, the access panels, and the fridge are the only things remaining to be mounted but also already cut and ready. I've started the electronics by making the power distribution system and I've burnt the tip of the soldering iron in doing so 🙃. it's my second time soldering and it was already half the way burnt from my practicing tries but thank god it's super cheap to get in Egypt and I'll get it out of pocket. my cousin (we both got raised together and basically brothers) got me to meet his electrician friend to teach me soldering but he didn't help me at all tbh. my body started to heal, the flu is almost gone, my emotional state is meah due to my personal life being at peak chaos lately but alhmdullah I'm managing 🤡. that's it for today. also finally I stopped working in the balcony since the wood working is over.

### Sep 20th, 2026
Today was chaotic, it was my second day working on the electronics, first I made a power distributor for the ultrasonic modules, and it went great. Then I used the Arduino’s voltage regulator to step down the 12V to 5V for that power distributor. I tested it with the multimeter and the readings were super clean and I was super happy. Then I focused on my circuit diagram to see what to do next, holding the multimeter's probe in my left hand. I wasn't minding my hand and it drifted and touched the Arduino's 5V and gnd pins at once. I heard a faint click and smelt burnt toast, i unplugged immediately. When I plugged it back in it got super hot because it was fried and when I measured it it outputted 7V, which obviously fried the ATmega chip (I mean duh 🙄). I got hit with a sudden 20-30 minutes of depression, putting my hands over my head and regretting my life choices. Then I said alhamdulillah whatever happened happened. I texted the guy who reviewed my project for funding. He seemed chill and forwarded it to his team. Worst case scenario, I’ll have to use my own non-original Arduino Uno and figure out how to jam everything with fewer gpio pins. Best case (which inshallah most likely to happen) they give me $20 to buy a new Mega. To save time since StarDance ends on September 30, I moved on to the motors. I originally planned to use two H bridge drivers, but Gemini suggested using just one and wiring two motors in parallel per channel for differential steering. I did that but when I tested it, the motors didn't turn on. I realized I flipped the polarity by accident. I thought I fried the chip but when I swapped everything to the second driver, still nothing worked. I picked up the multimeter tested my main power distributor, and it showed zero. I checked the inline fuse I made yesterday, and it was burnt! The fuse blew when it sensed high amps from the reverse polarity, saving the 2 drivers Alhamdulillah! I changed the fuse and everything worked again. I'm really happy that my safety measures actually worked.

---

# Devlog #6: Unboxing, Sawdust Wars, and Smoking Arduinos

*– From Sep 17th to Sep 20th 2026 –*

The last four days have been an absolute fever dream.

All 58 components finally arrived in one piece! Huge shoutout to the local sellers who threw in thank-you notes, a car freshener, and a random red **Mike Wazowski** figurine inside the box with the **Arduino Mega**. Unhinged, but cute.

Naturally, right as everything landed, my body hit peak flu with brutal bone aches. But I pushed through to start assembly and prep the updated BOM. I had to cover a few out-of-pocket expenses for miscellaneous screws and hinges I forgot to calculate 🤦🏻. Also the only 3mm plywood I could source on Amazon that fit the budget came in ~30x50cm sheets, so I'm building this first physical prototype using the raw panels as is while keeping core frame dimensions intact.

Later on, I decided to cut wood. *Pro-tip: foldable handsaws are dangerous.* I pressed the release button with my hand in the folding track. A quick flash of blood and a mini heart attack later, it stopped bleeding, thank God. Despite my clumsiness, I cut the middle layer outer shell, fridge frame, logic board mount, and lower latching mechanism.

I blacked out from exhaustion right after and woke up to an immediate eviction notice from my grandma: *zero woodworking in the living room.* I relocated my entire workshop out to the balcony. It’s actually a great setup, plus I’ve made friends with the local balcony mouse who hangs out while I work.

Despite the flu, I finished the chassis over 2 days, prepared doors/panels, and packed up the gear to move back inside.

I started assembling electronics by wiring the main power rail. Within an hour, I completely scorched my soldering iron tip 🙃. Since tips are super cheap in Egypt, I’m replacing it out of pocket. My cousin set up a meeting with an electrician friend for a masterclass, but he wasn’t much help so I figured it out on my own. Health-wise, the flu is receding. Personal life is at peak chaos, but thank god we manage 🤡.

Then came one of the most chaotic testing days yet. I built a `5V` power distributor for the `HC-SR04`sensors, routing power through the Arduino Mega’s internal regulator to get `5V`. Multimeter read a clean `5.0V`. Pure satisfaction.

Then came the tragedy. While staring at my schematic to figure out the next step, I was holding the probe in my left hand. My hand drifted. The bare metal probe tip bridged the Arduino’s `5V` pin and `GND` pin simultaneously.

> *Faint click. Scent of burnt toast.*

I yanked the power cord instantly. Plugged back in, the board ran super hot. Multimeter showed the regulator blowing a raw `7V` straight into the `ATmega2560` chip. The brain of **EcoRover** was officially fried.

I spent 20-30 minutes in full despair, but thank god, what happened happened. I reached out to the Stardance grant reviewer to explain the short circuit. Worst case: I’ll fall back to my personal non-original **Arduino Uno** and figure out a massive GPIO multiplexing hack to run all 8 sensors and drivers on fewer pins. Best case scenario: They approve a \$20 grant top-up for a replacement Mega so I can stay on schedule before the September 30 deadline.

To keep momentum, I tested the drive motors. My CAD planned for 2 `L298N`s, but Gemini sayed using 1 driver and wiring motors in parallel for differential steering. I wired it, flipped the switch, and... total silence.

I panicked, thinking I blew the `L298N` driver. Swapped to my backup still zero power.

I probed the main power line: `0V`. Then I checked the inline safety fuse I wired earlier. The fuse wire was completely snapped! It blew the microsecond it sensed the high amp spike from my reverse polarity mistake, saving both motor drivers from getting destroyed.

Seeing a safety feature you designed actually perform its job in real-time and save hardware from your own clumsiness is an unmatched feeling. I replaced the tiny car fuse, flipped the switch, and the drive motors whirred right to life!

---

## 📌 Daily Log Updates

### Sep 21st, 2026
Today thank god went with no fatealities (RIP Arduino), Jay wanted a proof video that its toast, i sent him one. I made the cooling setup with the peltier module, which judging by the almost 2nd degree burn on my hand it gets really hot really fast. and I've added the rocker switch with no soldring cuz i still didnt get a new tip but using the good old egyptian electritians which is tying the wire with the pin in a really weird but super strong way then using tape and heat shrinks. And also I've been working to minimize the GPIO pins needed for the project just in case they didn't fund me, like for examble today instead of a siginal pin, 3 5Vs, and 3 GNDs for the fans and the relay controlling the peltier, my 2mb ram of a brain realized since it will be set to HIGH from setup and always, why don't I use the relay to control all, which saved like 4 pins or smth. like let's calculate the pins needed together, first input through VIN and output from 5V so thats 2 but we wont count that, 3 for the LEDs and buzzer, 4 from the H bridge, freaking 16 from the HC-SR04s, and 3 from the relay. which is total of 16 pins..... and we can't just jam that into the UNO. (Later) i'm back and we will use in that case multiplexing, we'll get all trig pins into one pin to fire at the same time and that saved us 6 more pins which makes it just enough but we risk siginal interference so after asking gemini it said (Recommended Separation (d2): Space the two sensors apart by at least 1/3 to 1/2 of the total face length. For example, on a 30 cm square chassis, space the sensor centers 10 cm to 15 cm apart. Edge Margin (d1 and d3): Keep each sensor roughly 1/4 of the face length away from the corners (e.g., 7.5 cm from the edge on a 30 cm chassis). Angling them outward by 5° to 10° helps cover the dead zones directly at the outer corners of the rover.Height & Obstacles: Mount them at least 5 cm to 10 cm above the ground surface. If placed too low, the bottom edge of the ultrasonic cone will bounce off the floor and trigger false obstacle detections.) Or we can use the half dead Mega to give the GPIO pins to the UNO but i'll search more into that, Its 8am, i still didn't sleep and i'm hallucinating, goodnight

### Sep 22nd, 2026
I just got off the phone with my legendary of a barber Ahmed, he told me today is a rush and I should go tomorrow but that's irrelevant. today I've got an idea to cut even more pins, which is since the relay will be triggered on setup, let's just skip the Arduino completely and make it that it lights up immediately the moment the power runs to the system. now the last thing on the Arduino itself if input through VIN and GND to get 12v down to 5v (or low-key we can just use the other H driver to do so which I feel is a bad idea but u never know ¯\_(ツ)_/¯). and the 9 pins from the HC-SR04s (while making all the trig into one pin), and the 4 motor control pins. but idk I'll see but that means that it's completely doable with the UNO without multiplexers nor using the half dead mega as one, I told Jay that I can get another UNO if another mega would be too much and then both of them will talk through Rx and Rt, but when I thought about it now I can completely pull it off with just the UNO (or I believe at least). I'll re-do it in fritzing real quick with the new adjustments and I'll see what I can do then I'll start to build the electronics into the physical build. (later) I've wroked myself to exhaustion, I've made the fridge, installed all the doors and the mounting system for the last 2 tiers. I've also laid the battery in its place and the H bridge and the motors, but hot glue doesnt hold the motors really well we have to find another way but i'm having a real headache so dont talk to me before tomorrow. GN, oh btw before i forget the battary was super heavy that I had to install the caster wheel i got, thank god for everything.

### Sep 23rd, 2026
I still haven't went to the barber, but I worked a TON, I had a goal of finishing the whole thing today, but it didn't work, but the most noticeable thing that I got scammed. u see the 12v fans were not working at all, i found out after I mounted them, I tried to trouble shoot it in its place but I had to take it off and test them individually, both no luck, which I swear I didn't fry, If I did I would've been truthful but this is already dead before I touched it, tbh the listing was sketchy, it's from a seller not Amazon and it was suspiciously cheap. now I've 2 options, call Amazon and return it (we're in Egypt so it doesn't really work like it sounds). or just eat it and just place it in it's place to demonstrate, which what I'm gonna do, while also keeping the peltier module off even though it does work but I'm not wishing to get another second degree burn. so keep it off. also speaking of destroyed things, I've been chosen among buku bukus (a little bg if u don't know what the hell this is: stardance made a little challenging where we fix the starship by gaining 5k of total work hours, and after the starship was fixed buku buku started destroying it, and the users became either buku buku who destroys the ship so stardance stays and beans who fix the starship to go back home and no more stardance).

### Sep 24th, 2026
OMG today I got accepted into the faculty of science, Cairo University 🥳. thank God for that. and to celebrate this I've decided to give myself today off (given the fact that stardance got extended till oct 31st).

### Sep 25th, 2026
we had no internet at home today and my mobile data plan wouldn't stand a chance against lapse (The software that films my work).

### Sep 26th, 2026
today a lot of things happend, the wheels are super fast I have to make the motors chill out a bit which means we need to remove the jumpers off of the H Bridge and use 2 more pins to control speed, and THANKKK GOD we have the last 2 available pins available before we run out of gpio pins on the UNO. the wheels weren't balanced enough so I had to remount 2 motors a bit back to increase the base area. the battery was super heavy to sit in the lowest teir and it made the motors lockup so I had to remount it on the middle teir which is now supper jammed but I've did a decent job on the cable management. I've realized for the second time that saws are dangerous because again I cut myself even nastier cut (which frankly I deserve for being idiot) when I was cutting a little room for one of the wheels to move. but thank God it's only outer skin and it stopped bleeding after 5 minutes. I ran out of Female-Male wires which is the last thing we need to mount the HC-SR04s and the rover is basically done, I'll get some from RAM on my way to college (aka where I'm supposed to be there at 9am but it's 6am and I still haven't slept), I'll catch a few hours then go to uni. see you later.

### Sep 29th, 2026
First day of college got me whipped i crashed all day so i didnt work + RAM was closed, second day i was wayy t exhasted to go to RAM so i went straight home. As for today i finally got back to work through pain, i've finised the HC-SR04s mounting and wiring, also remember when i said i'm good at cable managment? well.. throw that against the wall its a catstrophy.

### Sep 30th-is and Oct 1st, 2026
I really don't know what I did today but my sleep is fudged, I did some work on the HC-SR04s wiring, mounted the Arduino, mounted the H bridge and wired it up and installed the battery but it was powering up the Arduino just fine but there was no 5V output, I had a lecture and I needed to go cuz we gotta keep that gpa up. I'll continue working at night or tomorrow 6am max.

### Oct 6th, 2026
heyy long time no talk. college really chew me and about to spit me. everyday I come back home dead on my feet, with a headache and boneache, I study a little bit and then sleep to the next day to repeat the cycle. I'm sorry for this sudden stop. but tomorrow inshallah is the last day of it this week and I'll be able to finish the project tomorrow or the day after maximum. for now I'll go cuz I have chem lab, love u <3.

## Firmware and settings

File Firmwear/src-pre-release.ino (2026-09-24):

// Com Trigger pin for all us
#define TRIG_PIN 4

// Echo pins for the 8 us
const int echoPin[8] = {2, 3, 9, 10, A0, 13, 12, 11};
int distance[8];

// Motor driver direction control pins
#define ML1 7
#define ML2 5
#define MR1 6
#define MR2 8

// Indicator pins
#define Buzzer A1
#define LEDL   A2
#define LEDR   A3

void setup() {
  Serial.begin(9600);

  // Init common trigger pin
  pinMode(TRIG_PIN, OUTPUT);
  digitalWrite(TRIG_PIN, LOW);

  // Init echo pins as inputs
  for (int i = 0; i < 8; i++) {
    pinMode(echoPin[i], INPUT);
  }
  // Init motor control pins
  pinMode(ML1, OUTPUT);
  pinMode(ML2, OUTPUT);
  pinMode(MR1, OUTPUT);
  pinMode(MR2, OUTPUT);
  // Init alert and signal pins
  pinMode(Buzzer, OUTPUT);
  pinMode(LEDL, OUTPUT);
  pinMode(LEDR, OUTPUT);
  // Startup udio alert check
  digitalWrite(LEDL, HIGH);
  digitalWrite(LEDR, HIGH);
  digitalWrite(Buzzer, HIGH); 
  delay(300);          
  digitalWrite(Buzzer, LOW);
  digitalWrite(LEDL, LOW);
  digitalWrite(LEDR, LOW);
}

// Function to measure distance for a specific sensor index
int readDistance(int index) {
  // Trigger a 10us HIGH pulse to start measurement
  digitalWrite(TRIG_PIN, LOW);
  delayMicroseconds(2);
  digitalWrite(TRIG_PIN, HIGH);
  delayMicroseconds(10);
  digitalWrite(TRIG_PIN, LOW);

  // Read pulse width on target echo pin with a 25ms timeout (~400cm max range)
  long duration = pulseIn(echoPin[index], HIGH, 25000); 
  
  if (duration == 0) return 400; // Return max range if no echo received
  return duration * 0.034 / 2;    // Calculate distance in cm
}

void moveForward() {
  digitalWrite(LEDL, LOW);
  digitalWrite(LEDR, LOW);
  digitalWrite(Buzzer, LOW); 
  digitalWrite(ML1, HIGH);
  digitalWrite(ML2, LOW);
  digitalWrite(MR1, HIGH);
  digitalWrite(MR2, LOW);
}

void moveBackward() {
  digitalWrite(LEDL, HIGH);
  digitalWrite(LEDR, HIGH);
  digitalWrite(Buzzer, HIGH); 
  digitalWrite(ML1, LOW);
  digitalWrite(ML2, HIGH);
  digitalWrite(MR1, LOW);
  digitalWrite(MR2, HIGH);
}

void spinLeft() {
  digitalWrite(LEDL, HIGH);
  digitalWrite(LEDR, LOW);
  digitalWrite(Buzzer, LOW); 
  digitalWrite(ML1, LOW);
  digitalWrite(ML2, HIGH);
  digitalWrite(MR1, HIGH);
  digitalWrite(MR2, LOW);
}

void spinRight() {
  digitalWrite(LEDL, LOW);
  digitalWrite(LEDR, HIGH);
  digitalWrite(Buzzer, LOW); 
  digitalWrite(ML1, HIGH);
  digitalWrite(ML2, LOW);
  digitalWrite(MR1, LOW);
  digitalWrite(MR2, HIGH);
}

void Stop() {
  digitalWrite(ML1, LOW);
  digitalWrite(ML2, LOW);
  digitalWrite(MR1, LOW);
  digitalWrite(MR2, LOW);
  digitalWrite(LEDL, LOW);
  digitalWrite(LEDR, LOW);
  digitalWrite(Buzzer, LOW);
}

void loop() {
  // Read distances sequentially for all 8 sensors
  for (int f = 0; f < 8; f++) {
    distance[f] = readDistance(f);
    delay(10); // Short delay to reduce ultrasonic cross-talk interference
  }

  // Check minimum obstacle distance in front (sensors 0 and 1)
  int frontDistance = min(distance[0], distance[1]);

  if (frontDistance >= 20) {
    moveForward();
  } 
  else {
    Stop();
    delay(200);
    moveBackward();
    delay(500);

    // Turn toward the side with more clearance
    if (distance[6] > distance[2]) {
      spinLeft();
    } else {
      spinRight();
    }
    delay(600);
  }
}

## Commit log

2026-08-18 BOM update
    [BOM.csv]
2026-08-18 Resolved BOM merge conflict
    [BOM.csv]
2026-08-20 Create journal.md for EcoRover development
    Added a journal to document the development of EcoRover, including initial concepts, CAD designs, wiring struggles, and daily updates.
2026-08-20 Fix typo in current state link in README
    Corrected a typo in the README regarding the current state of the project.
2026-08-20 Fix typo in README regarding project state
    Corrected a typo in the current state note.
2026-08-20 Update journal with latest devlogs and daily logs
    Added new entries and updates to the journal, including progress on EcoRover development, CAD challenges, and wiring struggles.
2026-08-27 Changing from EGP to USD
    [BOM.csv]
2026-08-27 Clean up BOM.csv by removing comments and formatting
    Removed unnecessary comments and adjusted formatting.
    [BOM.csv]
2026-08-27 Enhance README with additional figure renders
    Added images to enhance the CAD & Wiring Schematics section.
2026-08-30 STEP file
    [EcoRover chase.step]
2026-08-30 Revise JOURNAL.md with project updates and issues
    Updated project journal with recent progress and challenges faced, including issues with firmware and CAD files.
2026-09-01 Update JOURNAL.md with project progress and challenges
    Documented the administrative challenges faced during the grant process, including banking issues and grant review feedback. Highlighted collaboration with VeryNile for a custom plate donation.
2026-09-08 Revise Sep 06th entry with updated image size
    Updated the entry for Sep 06th, 2026 to include a new image size for the plate from VeryNile.
2026-09-12 Add firmware section to README
    Added a section about the firmware that manages sensor data and movement.
2026-09-12 Update README with wiring details and acknowledgments
    Added a section on wiring and BOM creation, including acknowledgments and safety considerations.
2026-09-21 Update JOURNAL.md with electronics progress and issues
    Documented progress on electronics assembly and troubleshooting, including a short circuit incident with the Arduino Mega and subsequent safety measures that prevented further damage.
2026-09-21 Update BOM.csv with new items and prices
    Removed outdated items and added new components with updated prices and links in BOM.csv.
    [BOM.csv]
2026-09-22 Revise daily log for Sep 21st, 2026
    Updated daily log with details on project progress, GPIO pin optimization, and sensor placement considerations.
2026-09-23 Revise daily log for GPIO optimization and project updates
    Updated daily log with project progress and ideas for minimizing GPIO pin usage.
2026-09-24 Revise wiring details and add EcoRover V3
    Updated the wiring section to reflect changes and added information about the new board. Included images for EcoRover V3.
2026-09-24 Refactor motor control and distance measurement functions
    Refactor ultrasonic sensor handling and motor control functions for improved readability and maintainability.
2026-10-11 Revise Oct 11th entry to reflect current rover status
    Updated journal entry for Oct 10th, 2026, detailing progress and challenges with the rover project, including issues with stability and battery weight.
2026-10-22 Revise project status in README.md
    Updated the current state of the project in README.md to reflect filming and shipping progress.
2026-10-27 Update current project status in README
2026-10-27 Document final updates and reflections on EcoRover
    Added detailed reflections on the final stages of the EcoRover project, including personal achievements and challenges faced during the process.
